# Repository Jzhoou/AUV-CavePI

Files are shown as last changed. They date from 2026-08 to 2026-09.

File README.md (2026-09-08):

# AUV-CavePI

独立完成的水下机器人原型工程，当前重点是把机械结构、电源与密封方案推进到可复现、可检查的实物阶段。仓库保留 CAD、装配、电源管理、问题定位与测试记录，并明确区分已经验证的结果和仍待验证的能力。

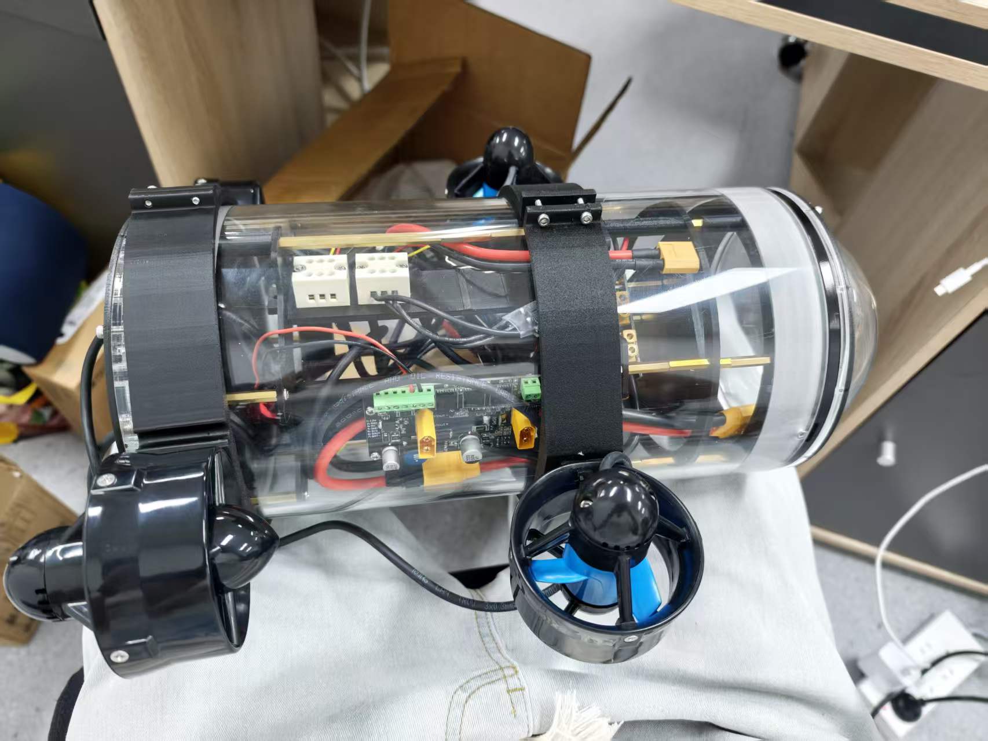
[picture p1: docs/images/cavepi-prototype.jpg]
CavePI 原型


## 项目概览

CavePI 采用 **160 × 300 mm 亚克力圆筒密封舱**、**3 个推进器**与 **14.8 V 4S 电源**。内部结构使用一体抽拉式支撑方案：支撑架一端与法兰配合，另一端不与法兰连接，可整体抽出，以降低安装、接线和维护难度。

本项目由我独立完成，工作覆盖：

- 根据密封舱与实物装配条件持续迭代 CAD，处理支撑结构、板卡布局、接口避让、推进器夹具和线槽等问题；
- 设计并试装一体抽拉式内部支撑，在有限舱内空间中兼顾固定、布线与维护；
- 规划 14.8 V 4S 电源路径及主干、分支接口，记录方案变化与待验证的带载能力；
- 完成穿线螺栓封灌、整机装配、漏点诊断和后续密封处理；
- 通过日志持续记录测试边界、失败现象、整改过程与下一步验证计划。

## 工程迭代

### 机械与 CAD

早期结构方案经过加工可行性和成本评估后转向 160 × 300 mm 成品亚克力密封舱，并据此调整内部支撑和外部安装结构。实物试装暴露了铜柱配合、螺母沉孔、接口干涉和内部高度等问题；CAD 随试装结果迭代，最终采用更便于接线和维护的一端法兰配合式一体抽拉支撑。

### 电源与推进布局

系统以 14.8 V 4S 电池为主电源，围绕电源管理、分电与下游负载规划供电路径。原型配置 3 个推进器；电源接口、线束空间和后续整机带载能力仍按工程日志继续核对，不把方案设计等同于性能验证。

### 密封问题定位

首次整机气密测试中，真空度无法稳定保持。使用泡沫水排查后，将漏点定位到穿线螺栓的线缆周边：封灌不充分且固化期间线缆位移造成开裂。随后对漏点进行二次处理，并在后续复测出现波动后进一步加入线皮打磨粗化、酒精清洁、线缆固定与过夜固化，再进行气密及分段浅水测试。

## 已验证结果

- **负压气密：** 以 15 inHg 为初始真空度保压 15 分钟，读数维持在 14–15 inHg。
- **分段浅水水密：** 受水缸尺寸限制，头部与尾部分别浸水 20 分钟；检查时舱内纸巾保持干燥。

以上结果仅对应当时的测试条件和装配状态。

## 尚未完成的验证

- 整机同时、完全浸没测试；
- 更长时间条件下的水密可靠性验证；
- 推进验证；
- 水下姿态控制验证；
- 定深控制验证。

因此，本仓库当前呈现的是水下机器人原型的工程进展，而不是已经完成全部水下能力验证的成品系统。

## 工程记录

- [项目日志汇总](项目日志汇总.md)
- [CAD v2.0 项目日志](<CAD_designs v2.0/项目日志.md>)
- [电源管理项目日志](电源管理/项目日志.md)

## English Summary

**AUV-CavePI is an independently developed underwater-robot prototype.** It uses a 160 × 300 mm acrylic pressure enclosure, three thrusters, a 14.8 V 4S power source, and an integrated slide-out internal support structure. The repository documents CAD iterations, physical assembly, power-distribution planning, and diagnosis and rework of a leak around cable-penetration bolts.

The verified results are deliberately limited to the recorded test conditions: the enclosure held an initial 15 inHg vacuum for 15 minutes while remaining between 14 and 15 inHg; the head and tail were then immersed separately for 20 minutes, and the paper towel inside remained dry. Full simultaneous immersion of the entire vehicle, long-duration watertightness, propulsion, attitude control, and depth-hold control have **not** yet been validated.

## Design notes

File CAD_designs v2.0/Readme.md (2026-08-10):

# SolidWork Design files of CavePI AUV

Due to large filesize of some parts, they are not uploaded directly to this repo. Please refer to this shared [Dropbox folder](https://www.dropbox.com/scl/fo/iza5p15aaolned5e47gp4/AAuj588nzsUPL_QK-2lGrOM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) to download all the files.

## Description

The parts are categorized into four groups.

- Exterior
  - Thruster
  - Sonar
  - Lights
  - ballast weights
- Interior (Computational enclosure)
  -  Battery junction
  -  Battery mounting plates (top, bottom, left, right, circular)
  -  Battery stack
  -  ESC
  -  Low light camera (downward camera)
  -  End cap
  -  O-ring flange
  -  Euro terminal strip
  -  Jetson Nano
  -  Mounting plate for Jetson Nano
  -  Raspberry Pi
  -  Mounting plate for Raspberry Pi
  -  Pixhawk
  -  Tether interface module
  -  Tube
-  Head
   - Fisheye camera
   - Dome connector
   - Dome retainer ring
   - Dome
 - Fasteners
   - Nuts, bolts, spacers and stand-offs

### Acknowledgements

We gratefully acknowledge the following entities for their the open-source CAD designs of various parts: Blue Robotics, GrabCAD, and McMaster-Carr.

| Part Name | 3D Model Owner / Referred From |
|---|---|
| Tube | Blue Robotics |
| End Cap | Blue Robotics |
| O-Ring Flange | Blue Robotics |
| Camera Low Light | Blue Robotics |
| Tether Interface Module | Blue Robotics |
| Basic ESC | Blue Robotics |
| Dome Retainer Ring | Blue Robotics |
| Dome | Blue Robotics |
| T200_Thruster | Blue Robotics |
| Sonar Bracket | Blue Robotics |
| Ping2 Sonar | Blue Robotics |
| Ballast Weight | Blue Robotics |
| Light | Blue Robotics |
| All fasteners | McMaster Carr |
| Jetson Nano | [GrabCAD](https://grabcad.com/library/nvidia-jetson-nano-2) |
| Raspberry Pi 5 | [GrabCAD](https://grabcad.com/library/raspberry-pi-5-2) |
| Pixhawk | [GrabCAD](https://grabcad.com/library/pixhawk-2-4-8-v1-flight-controller-1) |
| Fish-Eye Camera | [ArduCam](https://www.arducam.com/arducam-1080p-low-light-wdr-ultra-wide-angle-usb-camera-module-for-computer-2mp-cmos-imx291-160-degree-fisheye-mini-uvc-usb2-0-spy-webcam-boa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) |

## Example

The CAD assembly and the exploded view of CavePI is shown below:
<p align="center">
  cavepi_sys_gif
</p>

The 3D models of some of the parts in CavePI are shown below.
<p align="center">
  CAD Parts
</p>

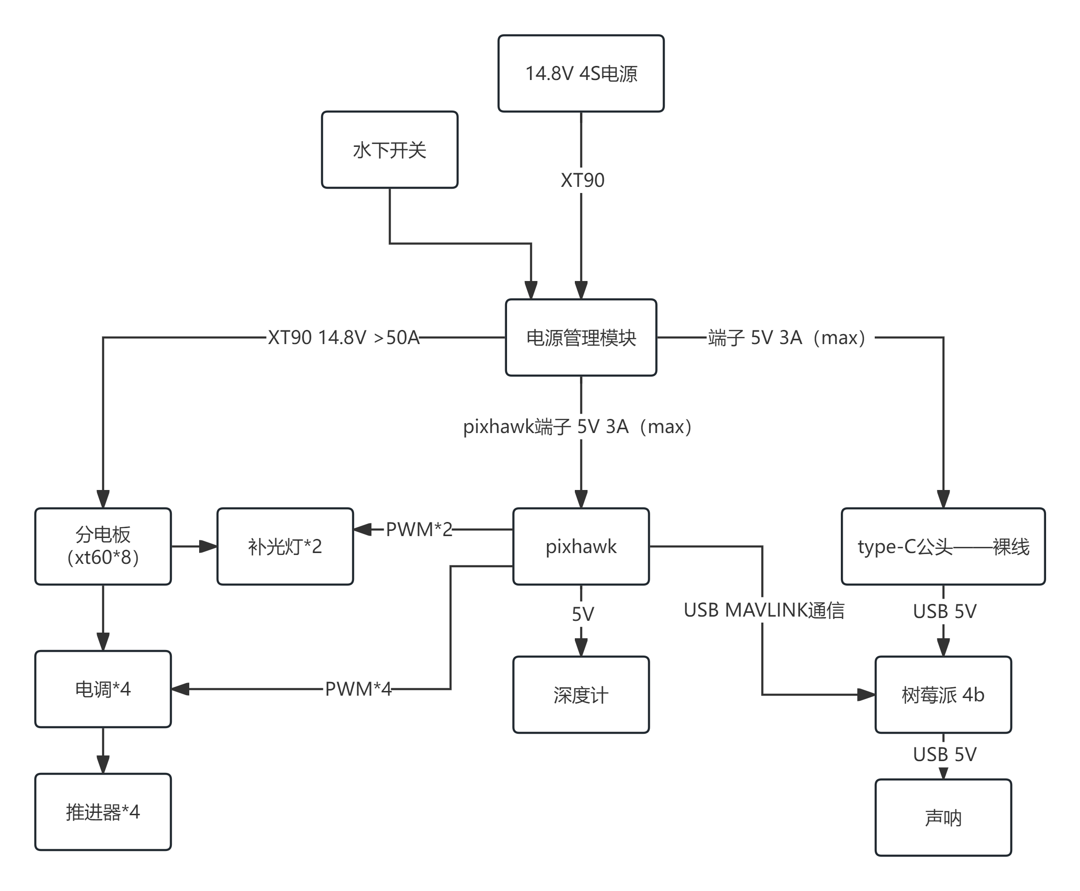
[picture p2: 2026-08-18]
电源管理/AUV电源管理方案2.0.png

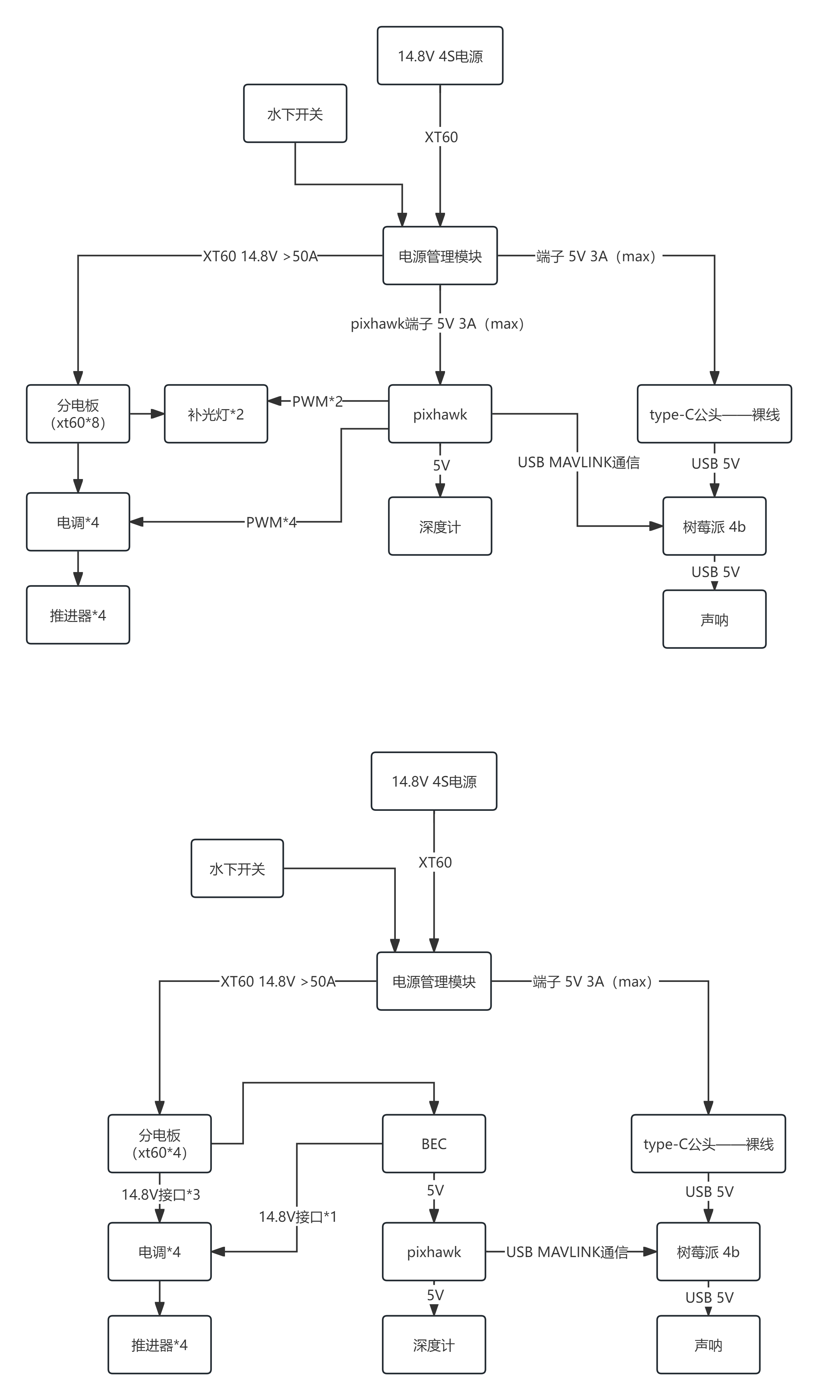
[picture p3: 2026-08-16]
电源管理/AUV电源管理方案.png

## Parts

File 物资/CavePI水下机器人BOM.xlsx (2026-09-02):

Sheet: BOM主表
CavePI 水下机器人 BOM 主表
口径：单台机器人；包含本体与装配耗材，不含通用工具。第一版按30 m设计深度、1-2 h续航目标管理，未完成工程验证的规格明确标记为待选型。
BOM物料数 |  |  | 第一版待购物料 |  |  | 第一版已知待购金额（元） |  |  | 待选型条目 |  |  | 说明：黄色表示存在采购缺口；浅红表示参数或型号尚未确认；灰色列为公式计算列。数量跨单位汇总仅供阶段规模参考。
68 |  |  | 21 |  |  | 0 |  |  | 23
物料编码 | 系统分类 | 装配层级 | 物料名称 | 规格/型号 | 单位 | 调试版需求量 | 第一版需求量 | 后续升级增量 | 现有可用数量 | 调试版待购量 | 第一版待购量 | 升级待购量 | 参考单价（元） | 调试版待购金额 | 第一版待购金额 | 升级待购金额 | 采购状态 | 来源资产编号 | 来源采购日期 | 备注
CPI-MECH-001 | 机械结构 | 一级部件 | 亚克力耐压舱筒体 | 外径160×有效筒长300 mm / 壁厚5 mm | 件 | 1 | 1 | 0 | 1 | 0 | 0 | 0 | 1145.00 | 0.00 | 0.00 | 0.00 | 已有 | ZC-20260818-005 | 2026-08-18 | 已购外径160×300mm整套密封舱，含亚克力圆管、半球罩、法兰、金属圈、端盖、密封圈、硅脂和配套螺丝；筒体壁厚、接口及30m耐压能力仍需到货验收和水压试验
CPI-MECH-002 | 机械结构 | 一级部件 | 耐压舱端盖 | 适配外径160 mm筒体 / 端盖结构与材料待确认 | 件 | 2 | 2 | 0 | 0 | 2 | 2 | 0 |  |  |  |  | 待选型 |  |  | 套装已含半球罩和端盖；具体数量、材料、厚度、密封槽及连接方式待到货核验，暂不冲减待购量
CPI-MECH-003 | 机械结构 | 二级部件 | 端盖压环/锁紧组件 | 与160 mm筒体及端盖匹配 | 套 | 2 | 2 | 0 | 0 | 2 | 2 | 0 |  |  |  |  | 待选型 |  |  | 套装已含法兰、金属圈和配套螺丝；数量、尺寸及锁紧结构待到货核验，暂不冲减待购量
CPI-SEAL-001 | 水密与线缆 | 二级部件 | 端盖O形密封圈 | 与端盖密封槽匹配 / 装机2件+备件2件 | 个 | 4 | 4 | 0 | 0 | 4 | 4 | 0 |  |  |  |  | 待选型 |  |  | 套装已含密封圈；数量、截面、材料及压缩率待到货核验，暂不冲减待购量
CPI-MECH-004 | 机械结构 | 一级部件 | 外部框架 | 耐腐蚀轻量框架 / 尺寸与材料待结构设计确认 | 套 | 1 | 1 | 0 | 0 | 1 | 1 | 0 |  |  |  |  | 待选型 |  |  | 建议模块化安装；需结合重心、浮心与推进器布局
CPI-MECH-005 | 机械结构 | 二级部件 | 舱内安装板 | 适配160×300 mm舱体 | 件 | 1 | 2 | 0 | 0 | 1 | 2 | 0 |  |  |  |  | 待选型 |  |  | 用于飞控、树莓派与电源模块分层安装
CPI-MECH-006 | 机械结构 | 二级部件 | 推进器安装支架 | 适配TS60 / 四推进器布局 | 个 | 1 | 4 | 0 | 0 | 1 | 4 | 0 |  |  |  |  | 待选型 |  |  | 支架角度按4自由度布置确认
CPI-MECH-007 | 机械结构 | 二级部件 | 浮力材料组件 | 闭孔浮力材料 / 目标微正浮力 | 套 | 1 | 1 | 0 | 0 | 1 | 1 | 0 |  |  |  |  | 待选型 |  |  | 需在整机称重后校核体积与布置
CPI-MECH-008 | 机械结构 | 二级部件 | 可调配重组件 | 耐腐蚀配重 / 可移动安装 | 套 | 1 | 1 | 0 | 0 | 1 | 1 | 0 |  |  |  |  | 待选型 | ZC-20260828-003 | 2026-08-28 | 已购5块×约200g纯铅配重；可移动安装结构、表面防腐与整机配平尚未确认，暂不冲减待购量
CPI-PROP-001 | 动力 | 一级部件 | TS60水下推进器 | 蓝黑500/12V | 个 | 1 | 4 | 0 | 4 | 0 | 0 | 0 | 189.00 | 0.00 | 0.00 | 0.00 | 已有 | ZC-20260713-009；ZC-20260818-003 | 2026-08-18 | 第一版四推进器已配齐：原有1个，本次新增3个
CPI-PROP-002 | 动力 | 一级部件 | 35A双向水下电调 | 35A / 双向无刷 / 水下动力 | 个 | 1 | 4 | 0 | 4 | 0 | 0 | 0 | 95.00 | 0.00 | 0.00 | 0.00 | 已有 | ZC-20260713-011；ZC-20260818-004 | 2026-08-18 | 第一版4个双向电调已配齐：原有1个，本次新增3个
CPI-POWER-001 | 电源 | 一级部件 | XT60 Hub分电板 | 一拖四扩展板/集线器 | 个 | 1 | 1 | 0 | 1 | 0 | 0 | 0 | 29.90 | 0.00 | 0.00 | 0.00 | 已有 | ZC-20260713-005 | 2026-07-13 | 动力母线分配
CPI-POWER-002 | 电源 | 一级部件 | 博立方电源模块 | 2S-12S / 5.3V BEC / XT60 | 个 | 1 | 1 | 0 | 1 | 0 | 0 | 0 | 71.24 | 0.00 | 0.00 | 0.00 | 已有 | ZC-20260713-006 | 2026-07-13 | 飞控电源与电压电流监测
CPI-POWER-003 | 电源 | 一级部件 | DC-DC 5V 10A降压模块 | QS-1205CBUM-10A | 个 | 1 | 1 | 0 | 1 | 0 | 0 | 0 | 17.60 | 0.00 | 0.00 | 0.00 | 已有 | ZC-20260729-001 | 2026-07-29 | 树莓派及低压设备供电
CPI-POWER-004 | 电源 | 一级部件 | ROV大电流电源控制板 | 5V/12V输出 / 板载大电流MOS开关 | 个 | 1 | 1 | 0 | 1 | 0 | 0 | 0 | 249.00 | 0.00 | 0.00 | 0.00 | 已有 | ZC-20260807-001 | 2026-08-07 | 主电源控制
CPI-POWER-005 | 电源 | 二级部件 | M10水下旋钮开关 | 大深水旋钮开关 / M10 | 个 | 1 | 1 | 0 | 1 | 0 | 0 | 0 | 93.58 | 0.00 | 0.00 | 0.00 | 已有 | ZC-20260807-002 | 2026-08-07 | 外部电源控制
CPI-POWER-006 | 电源 | 一级部件 | 调试用4S锂电池 | 14.8V 5000mAh / 长条 | 组 | 1 | 0 | 0 | 1 | 0 | 0 | 0 | 74.82 | 0.00 | 0.00 | 0.00 | 已有 | ZC-20260713-007 | 2026-07-13 | 仅用于调试，不作为第一版续航电池
CPI-POWER-007 | 电源 | 一级部件 | 第一版高容量动力电池 | 4S高放电锂电 / 建议20-30Ah区间 / 尺寸与容量待功耗实测 | 组 | 0 | 1 | 0 | 1 | 0 | 0 | 0 | 1552.00 | 0.00 | 0.00 | 0.00 | 部分已有 | ZC-20260825-003 | 2026-08-25 | 已购4S6P 14.8V 18Ah电池；容量低于建议20–30Ah，尺寸、持续放电能力及1–2h续航仍需实测
CPI-POWER-008 | 电源 | 二级部件 | 主回路保险丝座 | 适配4S动力母线 / 额定电流待实测 | 套 | 1 | 1 | 0 | 0 | 1 | 1 | 0 |  |  |  |  | 待选型 |  |  | 靠近电池正极布置
CPI-POWER-009 | 电源 | 二级部件 | 支路保险丝 | 推进器4路+低压与照明支路 / 规格待负载确认 | 个 | 3 | 6 | 0 | 0 | 3 | 6 | 0 |  |  |  |  | 待选型 |  |  | 按各支路最大工作电流选择
CPI-POWER-010 | 电源 | 二级部件 | XT60预制电源线 | XT60公头 / 12AWG / 30cm | 条 | 2 | 4 | 0 | 5 | 0 | 0 | 0 | 5.20 | 0.00 | 0.00 | 0.00 | 已有 | ZC-20260728-005 | 2026-07-28 | 现有采购为5条装
CPI-POWER-011 | 电源 | 三级部件 | 12AWG硅胶电源线 | 红黑双色 / 镀锡铜 | 米 | 2 | 5 | 0 | 0 | 2 | 5 | 0 |  |  |  |  | 待选型 |  |  | 长度按舱内布线复核
CPI-POWER-012 | 电源 | 三级部件 | Type-C大电流供电线 | 0.3m / Type-C公单头 / 0.5mm² | 条 | 1 | 1 | 0 | 1 | 0 | 0 | 0 | 4.98 | 0.00 | 0.00 | 0.00 | 已有 | ZC-20260810-001 | 2026-08-10 | 树莓派供电连接
CPI-CTRL-001 | 控制 | 一级部件 | 树莓派4B开发板 | 4B / 4GB | 块 | 1 | 1 | 0 | 1 | 0 | 0 | 0 | 1511.21 | 0.00 | 0.00 | 0.00 | 已有 | ZC-20260713-012 | 2026-07-13 | 第一版规划与控制计算平台
CPI-CTRL-002 | 控制 | 一级部件 | Pixhawk 2.4.8飞控 | 无GPS / 已刷ArduSub | 块 | 1 | 1 | 0 | 1 | 0 | 0 | 0 | 599.00 | 0.00 | 0.00 | 0.00 | 已有 | ZC-20260713-013 | 2026-07-13 | 姿态、深度与推进器控制
CPI-CTRL-003 | 控制 | 二级部件 | USB转TTL通讯模块 | Y804 / 5V TTL | 个 | 1 | 1 | 0 | 1 | 0 | 0 | 0 | 16.40 | 0.00 | 0.00 | 0.00 | 已有 | ZC-20260729-003 | 2026-07-29 | 调试与串口通信
CPI-CTRL-004 | 控制 | 二级部件 | microSD存储卡 | 64GB / A2级 / 高耐久 | 张 | 1 | 1 | 2 | 0 | 1 | 1 | 2 |  |  |  |  | 待选型 |  |  | 升级阶段为Jetson与树莓派5各预留1张
CPI-CTRL-005 | 控制 | 二级部件 | 树莓派散热组件 | 适配树莓派4B / 被动散热优先 | 套 | 1 | 1 | 0 | 0 | 1 | 1 | 0 |  |  |  |  | 待选型 |  |  | 密闭舱内需校核温升，不建议依赖舱内空气风扇
CPI-CTRL-006 | 控制 | 二级部件 | 舱内漏水检测模块 | 触点式或光电式 / Pixhawk兼容 | 个 | 1 | 1 | 0 | 0 | 1 | 1 | 0 |  |  |  |  | 待选型 |  |  | 建议作为第一版安全必备件
CPI-SENS-001 | 感知 | 一级部件 | MS5837深度计 | MS5837-30Ba TB30 | 个 | 1 | 1 | 0 | 1 | 0 | 0 | 0 | 199.00 | 0.00 | 0.00 | 0.00 | 已有 | ZC-20260713-010 | 2026-07-13 | 定深控制
CPI-SENS-002 | 感知 | 一级部件 | 水下测距传感器 | 3米量程 / 8-800cm | 个 | 1 | 1 | 0 | 1 | 0 | 0 | 0 | 103.00 | 0.00 | 0.00 | 0.00 | 已有 | ZC-20260713-008 | 2026-07-13 | 第一版基础测距；后续声呐升级不覆盖此件
CPI-LIGHT-001 | 照明 | 一级部件 | ROV探照灯 | ArduSub PWM / 2500lm / 8-30V / 100° | 盏 | 1 | 2 | 0 | 2 | 0 | 0 | 0 | 299.00 | 0.00 | 0.00 | 0.00 | 已有 | ZC-20260729-002；ZC-20260828-005 | 2026-08-28 | 第一版两盏探照灯已配齐：原有1盏，本次新增1盏；新增规格为6500K、ArduSub PWM、100°光束角，电压与水密性待实测
CPI-SEAL-002 | 水密与线缆 | 二级部件 | 主穿舱水密接头/电缆穿透件 | 适配30 m设计深度 / 口径和数量按线缆表确认 | 个 | 5 | 8 | 4 | 9 | 0 | 0 | 3 | 30.00 | 0.00 | 0.00 | 90.00 | 部分已有 | ZC-20260818-002 | 2026-08-18 | 本次购M10穿线螺丝9个，第一版需求8个已覆盖并余1个；后续升级仍需按线缆表复核
CPI-SEAL-003 | 水密与线缆 | 二级部件 | 泄压/抽真空测试阀 | 耐压舱检漏接口 | 个 | 1 | 1 | 0 | 0 | 1 | 1 | 0 |  |  |  |  | 待选型 |  |  | 用于负压检漏和压力测试流程
CPI-SEAL-004 | 水密与线缆 | 三级部件 | O形圈硅脂 | 水下密封兼容 / 不腐蚀密封材料 | 份 | 1 | 1 | 0 | 1 | 0 | 0 | 0 | 49.00 | 0.00 | 0.00 | 0.00 | 已有 | ZC-20260828-001 | 2026-08-28 | 已购ROV专用防水密封硅脂；数量覆盖第一版，但与实际O形圈材料的相容性仍需到货核验
CPI-SEAL-005 | 水密与线缆 | 三级部件 | 灌封胶/海工环氧 | 电缆穿舱灌封 / 与线皮和舱体材料兼容 | 份 | 1 | 1 | 1 | 2 | 0 | 0 | 0 | 75.00 | 0.00 | 0.00 | 0.00 | 已有 | ZC-20260825-002；ZC-20260828-002 | 2026-08-28 | 已有黑色快干AB环氧胶与专用穿线密封胶各1份，覆盖第一版及升级阶段数量；仍需完成长期浸泡、材料相容性及固化工艺试验
CPI-SEAL-006 | 水密与线缆 | 三级部件 | 热缩管套装 | 含胶双壁 / 多规格 | 套 | 1 | 1 | 0 | 0 | 1 | 1 | 0 |  |  |  |  | 待选型 |  |  | 舱内线束绝缘与应力保护
CPI-NET-001 | 水密与线缆 | 调试附件 | 调试网线 | CAT6 / 建议35 m含余量 | 米 | 35 | 0 | 0 | 0 | 35 | 0 | 0 |  |  |  |  | 待选型 |  |  | 仅调试版保留，第一版不配置网线脐带
CPI-NET-002 | 水密与线缆 | 调试附件 | 网线水密穿舱组件 | CAT6兼容 / 30 m级水密 | 套 | 1 | 0 | 0 | 0 | 1 | 0 | 0 |  |  |  |  | 待选型 |  |  | 仅调试版
CPI-NET-003 | 水密与线缆 | 调试附件 | 网线应力释放与水面连接组件 | 适配35 m调试网线 | 套 | 1 | 0 | 0 | 0 | 1 | 0 | 0 |  |  |  |  | 待选型 |  |  | 仅调试版，避免拉力直接作用于穿舱件
CPI-CONS-001 | 装配耗材 | 三级部件 | M3×6不锈钢螺钉 | 304十字圆头 | 个 | 8 | 12 | 4 | 100 | 0 | 0 | 0 | 0.02 | 0.00 | 0.00 | 0.00 | 已有 | ZC-20260722-019 | 2026-07-22 | 装机建议量；最终随结构图复核
CPI-CONS-002 | 装配耗材 | 三级部件 | M3×10不锈钢螺钉 | 304十字圆头 | 个 | 8 | 12 | 4 | 100 | 0 | 0 | 0 | 0.03 | 0.00 | 0.00 | 0.00 | 已有 | ZC-20260722-018 | 2026-07-22 | 装机建议量；最终随结构图复核
CPI-CONS-003 | 装配耗材 | 三级部件 | M3×12不锈钢螺钉 | 304内六角 | 个 | 8 | 16 | 4 | 100 | 0 | 0 | 0 | 0.03 | 0.00 | 0.00 | 0.00 | 已有 | ZC-20260722-014 | 2026-07-22 | 装机建议量；最终随结构图复核
CPI-CONS-004 | 装配耗材 | 三级部件 | M3×20不锈钢螺钉 | 304十字圆头机牙 | 个 | 4 | 8 | 4 | 100 | 0 | 0 | 0 | 0.05 | 0.00 | 0.00 | 0.00 | 已有 | ZC-20260803-002 | 2026-08-03 | 装机建议量；最终随结构图复核
CPI-CONS-005 | 装配耗材 | 三级部件 | M3防松锁紧螺母 | 304材质 | 个 | 12 | 24 | 8 | 40 | 0 | 0 | 0 | 0.05 | 0.00 | 0.00 | 0.00 | 已有 | ZC-20260803-003 | 2026-08-03 | 推进器及框架连接优先使用
CPI-CONS-006 | 装配耗材 | 三级部件 | M3六角螺母 | 304材质 | 个 | 12 | 24 | 8 | 100 | 0 | 0 | 0 | 0.02 | 0.00 | 0.00 | 0.00 | 已有 | ZC-20260722-013 | 2026-07-22 | 装机建议量
CPI-CONS-007 | 装配耗材 | 三级部件 | M3平垫圈 | 304 / M3×6×0.5 | 个 | 16 | 32 | 8 | 200 | 0 | 0 | 0 | 0.02 | 0.00 | 0.00 | 0.00 | 已有 | ZC-20260722-007 | 2026-07-22 | 装机建议量
CPI-CONS-008 | 装配耗材 | 三级部件 | M3铜柱12mm | M3×12+3 | 支 | 4 | 4 | 4 | 50 | 0 | 0 | 0 | 0.17 | 0.00 | 0.00 | 0.00 | 已有 | ZC-20260722-001 | 2026-07-22 | 板卡安装
CPI-CONS-009 | 装配耗材 | 三级部件 | M3铜柱20mm | M3×20+3 | 支 | 4 | 4 | 4 | 70 | 0 | 0 | 0 | 0.26 | 0.00 | 0.00 | 0.00 | 已有 | ZC-20260722-004；ZC-20260817-004 | 2026-08-17 | 板卡安装；现有50支M3×20+3，另购20支M3×20+6，装配前确认螺柱端长度
CPI-CONS-010 | 装配耗材 | 三级部件 | 管型端子 | VE1508等 / 按线径选用 | 个 | 12 | 24 | 12 | 1200 | 0 | 0 | 0 | 0.01 | 0.00 | 0.00 | 0.00 | 已有 | ZC-20260722-021 | 2026-07-22 | 从现有1200只套装中领用
CPI-CONS-011 | 装配耗材 | 三级部件 | 3位接线端子连接器 | H3802-15A-03 / 白色 | 个 | 2 | 4 | 2 | 5 | 0 | 0 | 1 | 4.98 | 0.00 | 0.00 | 4.98 | 部分已有 | ZC-20260722-022 | 2026-07-22 | 现有5个
CPI-CONS-012 | 装配耗材 | 三级部件 | 电工绝缘胶带 | PVC阻燃防水 | 卷 | 1 | 1 | 1 | 2 | 0 | 0 | 0 | 2.50 | 0.00 | 0.00 | 0.00 | 已有 | ZC-20260807-006 | 2026-08-07 | 仅作辅助绝缘，不作为耐压舱主密封
CPI-CONS-013 | 装配耗材 | 三级部件 | 电子焊接锡丝 | 无铅低温 / 自带松香 | 份 | 1 | 1 | 1 | 1 | 0 | 0 | 1 | 15.80 | 0.00 | 0.00 | 15.80 | 部分已有 | ZC-20260713-001；ZC-20260830-001 | 2026-08-30 | 原有1份无铅低温锡丝；本次新增2卷63%含锡焊丝，可用于调试，但不等同无铅规格，暂不增加BOM合规可用数量
CPI-CONS-014 | 装配耗材 | 三级部件 | 尼龙扎带与线束固定座 | 多规格 / 耐潮 | 套 | 1 | 1 | 1 | 0 | 1 | 1 | 1 |  |  |  |  | 部分已有 | ZC-20260826-006 | 2026-08-26 | 已购4×150mm黑色尼龙扎带500根；未见线束固定座，暂不冲减套件待购量
CPI-CONS-015 | 装配耗材 | 三级部件 | 中强度螺纹锁固剂 | 适用于不锈钢紧固件 | 份 | 1 | 1 | 1 | 0 | 1 | 1 | 1 |  |  |  |  | 待选型 |  |  | 避免使用永久高强度型号
CPI-SAFE-001 | 安全回收 | 一级部件 | 安全回收绳 | 低伸长高强度绳 / 建议35 m含余量 | 米 | 10 | 35 | 0 | 0 | 10 | 35 | 0 |  |  |  |  | 待选型 |  |  | 完整版无网线脐带，保留独立安全回收措施
CPI-SAFE-002 | 安全回收 | 二级部件 | 不锈钢卸扣/连接环 | 耐腐蚀 / 与回收绳及框架匹配 | 个 | 2 | 2 | 0 | 0 | 2 | 2 | 0 |  |  |  |  | 待选型 |  |  | 设置独立承力点
CPI-SAFE-003 | 安全回收 | 二级部件 | 高可视识别标识 | 橙色或荧光耐水标识 | 套 | 1 | 1 | 0 | 0 | 1 | 1 | 0 |  |  |  |  | 待选型 |  |  | 便于水面与水下识别
CPI-UPG-001 | 后续升级 | 一级部件 | Jetson Nano计算平台 | 视觉感知计算 / 型号与内存版本待选 | 套 | 0 | 0 | 1 | 0 | 0 | 0 | 1 |  |  |  |  | 可选升级 |  |  | 参考公开CavePI视觉计算架构
CPI-UPG-002 | 后续升级 | 一级部件 | 树莓派5开发板 | 规划与控制计算 / 内存版本待选 | 套 | 0 | 0 | 1 | 0 | 0 | 0 | 1 |  |  |  |  | 可选升级 |  |  | 后续版本升级计算平台
CPI-UPG-003 | 后续升级 | 一级部件 | 前视低照度摄像头 | 水下低照度 / 视场角与接口待选 | 套 | 0 | 0 | 1 | 0 | 0 | 0 | 1 |  |  |  |  | 可选升级 |  |  | 第一版不配置摄像头
CPI-UPG-004 | 后续升级 | 一级部件 | 下视低照度摄像头 | 引导线识别 / 视场角与接口待选 | 套 | 0 | 0 | 1 | 0 | 0 | 0 | 1 |  |  |  |  | 可选升级 |  |  | 第一版不配置摄像头
CPI-UPG-005 | 后续升级 | 二级部件 | 摄像头水密窗口/舱体 | 前视+下视 / 30 m级 / 光学窗口 | 套 | 0 | 0 | 2 | 0 | 0 | 0 | 2 |  |  |  |  | 可选升级 |  |  | 需与摄像头视场和舱体布局匹配
CPI-UPG-006 | 后续升级 | 一级部件 | Ping2级声呐测距模块 | 障碍测距 / 具体型号待选 | 套 | 0 | 0 | 1 | 0 | 0 | 0 | 1 |  |  |  |  | 可选升级 |  |  | 用于远距离测距避障
CPI-UPG-007 | 后续升级 | 可选系统 | DVL水下速度计 | 水下速度/里程推算 / 量程与接口待选 | 套 | 0 | 0 | 1 | 0 | 0 | 0 | 1 |  |  |  |  | 可选升级 |  |  | 定位建图方案选配，成本较高
CPI-UPG-008 | 后续升级 | 可选系统 | 水声定位系统 | USBL/LBL方案待论证 | 套 | 0 | 0 | 1 | 0 | 0 | 0 | 1 |  |  |  |  | 可选升级 |  |  | 定位建图方案选配
CPI-UPG-009 | 后续升级 | 可选系统 | 成像声呐 | 水下建图 / 频率与量程待选 | 套 | 0 | 0 | 1 | 0 | 0 | 0 | 1 |  |  |  |  | 可选升级 |  |  | 建图方案选配
CPI-UPG-010 | 后续升级 | 二级部件 | 高速固态存储 | 512GB / 高耐久 | 块 | 0 | 0 | 1 | 0 | 0 | 0 | 1 |  |  |  |  | 可选升级 |  |  | 记录双摄像头与声呐数据

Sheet: 阶段采购汇总
CavePI 阶段采购汇总
调试版、第一版和后续升级的数量与采购缺口均自动引用BOM主表。跨单位数量合计仅用于规模参考。
阶段 | 需求物料种类 | 需求数量合计（混合单位） | 已有覆盖物料种类 | 待购物料种类 | 待购数量合计（混合单位） | 已知单价覆盖物料种类 | 已知待购金额（元） | 待选型物料种类
调试版 | 57 | 193 | 33 | 24 | 76 | 33 | 0.00 | 23
第一版 | 54 | 277 | 33 | 21 | 74 | 33 | 0.00 | 20
后续升级 | 28 | 84 | 15 | 16 | 20 | 15 | 110.78 | 2
来源核对：采购清单共100类、141件，采购总额9402.88元；资产清单中运费、快递费与打包费未纳入资产。本表只匹配机器人本体与装配耗材。

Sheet: 现有资产匹配
现有资产与 CavePI BOM 匹配
逐条保留资产清单来源。匹配结论用于库存识别，不改变原资产记录；通用工具和非本体费用不计入单台BOM。
资产编号 | 管理类别 | 资产属性 | 资产名称 | 规格/型号 | 采购数量 | 单价（元） | 资产原值（元） | 购置日期 | 供应商/店铺 | 匹配BOM编码 | 匹配结论 | 说明
ZC-20260713-001 | 材料耗材 | 低值易耗品 | 绿林高纯度锡丝 | 自带松香/无铅低温 | 1 | 15.80 | 15.80 | 2026-07-13 | 绿林官方旗舰店 | CPI-CONS-013 | 装配耗材
ZC-20260713-002 | 材料耗材 | 低值易耗品 | 绿林烙铁头（刀头） | 通用936内热式 | 4 | 2.61 | 10.44 | 2026-07-13 | 绿林官方旗舰店 |  | 通用工具不纳入 | 用于装配或调试，不计入单台机器人
ZC-20260713-003 | 工具器具 | 可周转资产 | 绿林电烙铁 | 60W可调温 | 1 | 25.80 | 25.80 | 2026-07-13 | 绿林官方旗舰店 |  | 通用工具不纳入 | 用于装配或调试，不计入单台机器人
ZC-20260713-004 | 设备及装置 | 可周转资产 | 80W航模平衡充电器 | BT2.0第3版/支持1-6S | 1 | 149.90 | 149.90 | 2026-07-13 | 零轴电子科技企业店 |  | 通用工具不纳入 | 用于装配或调试，不计入单台机器人
ZC-20260713-005 | 电子元器件 | 项目组件 | XT60 Hub分电板 | 一拖四扩展板/集线器 | 1 | 29.90 | 29.90 | 2026-07-13 | Autoro电子科技 | CPI-POWER-001 | 直接使用 | 原备注：14
ZC-20260713-006 | 电子元器件 | 项目组件 | 博立方电源模块 | 支持2S-12S/带5.3V BEC/XT60 | 1 | 71.24 | 71.24 | 2026-07-13 | 博立方无人机企业店 | CPI-POWER-002 | 直接使用 | 原备注：14
ZC-20260713-007 | 设备及装置 | 可周转资产 | 航模锂电池 | 14.8V 5000mAh 长条 | 1 | 74.82 | 74.82 | 2026-07-13 | 阳河科技 | CPI-POWER-006 | 直接使用 | 5000mAh仅做调试使用，后续再选择大容量电池
ZC-20260713-008 | 仪器仪表 | 可周转资产 | 水下测距传感器 | 3米量程/8-800cm | 1 | 103.00 | 103.00 | 2026-07-13 | 深圳市电应普科技 | CPI-SENS-002 | 直接使用 | 原备注：14
ZC-20260713-009 | 设备及装置 | 可周转资产 | TS60水下推进器 | 蓝黑500/12V | 1 | 189.00 | 189.00 | 2026-07-13 | 淘宝店铺 | CPI-PROP-001 | 部分使用 | 现有数量不足第一版需求，缺口见BOM主表
ZC-20260713-010 | 仪器仪表 | 可周转资产 | 深度计 | MS5837-30Ba TB30 | 1 | 199.00 | 199.00 | 2026-07-13 | 淘宝店铺 | CPI-SENS-001 | 直接使用
ZC-20260713-011 | 设备及装置 | 可周转资产 | 双向无刷电机电调 | 35A水下动力 | 1 | 95.00 | 95.00 | 2026-07-13 | 淘宝店铺 | CPI-PROP-002 | 部分使用 | 现有数量不足第一版需求，缺口见BOM主表
ZC-20260713-012 | 设备及装置 | 可周转资产 | 树莓派4B开发板 | 4B/4G基础套餐 | 1 | 1511.21 | 1511.21 | 2026-07-13 | 淘宝店铺 | CPI-CTRL-001 | 直接使用
ZC-20260713-013 | 设备及装置 | 可周转资产 | Pixhawk 2.4.8飞控 | 无GPS/刷好Ardusub | 1 | 599.00 | 599.00 | 2026-07-13 | 初将科技 | CPI-CTRL-002 | 直接使用
ZC-20260721-001 | 工具器具 | 可周转资产 | 德力西小螺丝刀套装 | 45合一/S2+CR-V材质 | 1 | 27.70 | 27.70 | 2026-07-21 | 德力西手动工具旗舰店 |  | 通用工具不纳入 | 用于装配或调试，不计入单台机器人
ZC-20260722-001 | 材料耗材 | 低值易耗品 | 单头六角铜柱 | M3×12+3/50支 | 1 | 8.41 | 8.41 | 2026-07-22 | 固万基官方旗舰店 | CPI-CONS-008 | 装配耗材 | 确认订单优惠后价格
ZC-20260722-002 | 材料耗材 | 低值易耗品 | 单头六角铜柱 | M3×6+3/100支 | 1 | 10.93 | 10.93 | 2026-07-22 | 固万基官方旗舰店 |  | 非本体采购不纳入 | 确认订单优惠后价格
ZC-20260722-003 | 材料耗材 | 低值易耗品 | 单头六角铜柱 | M3×15+3/50支 | 1 | 10.93 | 10.93 | 2026-07-22 | 固万基官方旗舰店 |  | 非本体采购不纳入 | 确认订单优惠后价格
ZC-20260722-004 | 材料耗材 | 低值易耗品 | 单头六角铜柱 | M3×20+3/50支 | 1 | 12.46 | 12.46 | 2026-07-22 | 固万基官方旗舰店 | CPI-CONS-009 | 装配耗材 | 确认订单优惠后价格
ZC-20260722-005 | 材料耗材 | 低值易耗品 | 304不锈钢平垫圈 | M5×8×0.5/200只 | 1 | 4.04 | 4.04 | 2026-07-22 | 固万基官方旗舰店 |  | 非本体采购不纳入 | 确认订单优惠后价格
ZC-20260722-006 | 材料耗材 | 低值易耗品 | 304不锈钢平垫圈 | M4×7×0.5/200只 | 1 | 3.19 | 3.19 | 2026-07-22 | 固万基官方旗舰店 |  | 非本体采购不纳入 | 确认订单优惠后价格
ZC-20260722-007 | 材料耗材 | 低值易耗品 | 304不锈钢平垫圈 | M3×6×0.5/200只 | 1 | 3.19 | 3.19 | 2026-07-22 | 固万基官方旗舰店 | CPI-CONS-007 | 装配耗材 | 确认订单优惠后价格
ZC-20260722-008 | 材料耗材 | 低值易耗品 | 单头六角铜柱 | M3×100+6/5支 | 1 | 9.46 | 9.46 | 2026-07-22 | 固万基官方旗舰店 |  | 非本体采购不纳入 | 确认订单优惠后价格
ZC-20260722-009 | 材料耗材 | 低值易耗品 | 单头六角铜柱 | M3×24+3/20支 | 1 | 7.06 | 7.06 | 2026-07-22 | 固万基官方旗舰店 |  | 非本体采购不纳入 | 确认订单优惠后价格
ZC-20260722-010 | 仪器仪表 | 可周转资产 | 数字万用表 | 多功能智能防烧/标配+备用电池 | 1 | 18.60 | 18.60 | 2026-07-22 | 嘉华仪器仪表批发中心 |  | 通用工具不纳入 | 用于装配或调试，不计入单台机器人
ZC-20260722-011 | 材料耗材 | 低值易耗品 | 304不锈钢六角螺母 | M5/50个 | 1 | 2.26 | 2.26 | 2026-07-22 | 楚卫旗舰店 |  | 非本体采购不纳入 | 确认订单优惠后价格
ZC-20260722-012 | 材料耗材 | 低值易耗品 | 304不锈钢六角螺母 | M4/100个 | 1 | 3.18 | 3.18 | 2026-07-22 | 楚卫旗舰店 |  | 非本体采购不纳入 | 确认订单优惠后价格
ZC-20260722-013 | 材料耗材 | 低值易耗品 | 304不锈钢六角螺母 | M3/100个 | 1 | 2.09 | 2.09 | 2026-07-22 | 楚卫旗舰店 | CPI-CONS-006 | 装配耗材 | 确认订单优惠后价格
ZC-20260722-014 | 材料耗材 | 低值易耗品 | 304内六角螺钉 | M3×12/100个 | 1 | 2.60 | 2.60 | 2026-07-22 | 楚卫旗舰店 | CPI-CONS-003 | 装配耗材 | 确认订单优惠后价格
ZC-20260722-015 | 材料耗材 | 低值易耗品 | 304十字圆头螺钉 | M5×12/50个 | 1 | 4.78 | 4.78 | 2026-07-22 | 佰瑞特官方旗舰店 |  | 非本体采购不纳入 | 确认订单优惠后价格
ZC-20260722-016 | 材料耗材 | 低值易耗品 | 304十字圆头螺钉 | M4×12/50个 | 1 | 2.75 | 2.75 | 2026-07-22 | 佰瑞特官方旗舰店 |  | 非本体采购不纳入 | 确认订单优惠后价格
ZC-20260722-017 | 材料耗材 | 低值易耗品 | 304十字圆头螺钉 | M4×10/100个 | 1 | 4.95 | 4.95 | 2026-07-22 | 佰瑞特官方旗舰店 |  | 非本体采购不纳入 | 确认订单优惠后价格
ZC-20260722-018 | 材料耗材 | 低值易耗品 | 304十字圆头螺钉 | M3×10/100个 | 1 | 2.96 | 2.96 | 2026-07-22 | 佰瑞特官方旗舰店 | CPI-CONS-002 | 装配耗材 | 确认订单优惠后价格
ZC-20260722-019 | 材料耗材 | 低值易耗品 | 304十字圆头螺钉 | M3×6/100个 | 1 | 2.34 | 2.34 | 2026-07-22 | 佰瑞特官方旗舰店 | CPI-CONS-001 | 装配耗材 | 确认订单优惠后价格
ZC-20260722-020 | 工具器具 | 可周转资产 | 接线端子压线钳 | HSC8 6-4A/0.25-10mm²/四边形 | 1 | 16.90 | 16.90 | 2026-07-22 | 德力西聚优品专卖店 |  | 通用工具不纳入 | 用于装配或调试，不计入单台机器人
ZC-20260722-021 | 材料耗材 | 低值易耗品 | 管型端子套装 | VE1508针形铜鼻子/8种规格/1200只 | 1 | 17.82 | 17.82 | 2026-07-22 | UTL尤提乐岚行专卖店 | CPI-CONS-010 | 装配耗材 | 确认订单优惠后价格
ZC-20260722-022 | 材料耗材 | 低值易耗品 | 迷你接线端子连接器 | H3802-15A-03/3位/白色 | 5 | 4.98 | 24.90 | 2026-07-22 | elinkerelectric旗舰店 | CPI-CONS-011 | 装配耗材 | 确认订单优惠后价格
ZC-20260724-001 | 设备及装置 | 可周转资产 | 12V锂电池充电器 | 12-12.6V/1A-2A/5.5mm圆孔/线长1米 | 1 | 12.50 | 12.50 | 2026-07-24 | 浩可充电器实力工厂 |  | 通用工具不纳入 | 用于装配或调试，不计入单台机器人
ZC-20260724-002 | 设备及装置 | 可周转资产 | 公牛六位总控插座 | B9330/全长1.8米 | 1 | 38.00 | 38.00 | 2026-07-24 | 公牛多德专卖店 |  | 通用工具不纳入 | 用于装配或调试，不计入单台机器人
ZC-20260728-002 | 材料耗材 | 低值易耗品 | 单头六角铜柱 | M3*24+6（20支） | 1 | 8.01 | 8.01 | 2026-07-28 | 固万基官方旗舰店 |  | 非本体采购不纳入 | 优惠后价；先用后付
ZC-20260728-003 | 材料耗材 | 低值易耗品 | 单头六角铜柱 | M3*37+6（20支） | 1 | 14.40 | 14.40 | 2026-07-28 | 固万基官方旗舰店 |  | 非本体采购不纳入 | 优惠后价；先用后付
ZC-20260728-004 | 工具器具 | 可周转资产 | 钳子三件套 | 8寸工业级套装（老虎钳+斜嘴钳+尖嘴钳） | 1 | 26.27 | 26.27 | 2026-07-28 | 天天特卖工厂 |  | 通用工具不纳入 | 用于装配或调试，不计入单台机器人
ZC-20260728-005 | 电子元器件 | 项目组件 | XT60公母插头 | XT60公头12AWG，3.4平方，30厘米，5条 | 1 | 26.00 | 26.00 | 2026-07-28 | 创未良品电子科技有限公司 | CPI-POWER-010 | 直接使用 | 优惠后价；先用后付
ZC-20260729-001 | 电子元器件 | 项目组件 | DC-DC降压模块 | QS-1205CBUM-10A / DC-DC 5V 10A | 1 | 17.60 | 17.60 | 2026-07-29 | 深圳市优信电子科技有限公司 | CPI-POWER-003 | 直接使用 | 实付款17.60元
ZC-20260729-002 | 设备及装置 | 可周转资产 | 水下机器人ROV探照灯 | Ardusub脉宽控制 / 光束角100° / 2500流明 / 8-30V宽压 / PWM驱动 | 1 | 306.00 | 306.00 | 2026-07-29 | EXOCEAN拓洲智能 | CPI-LIGHT-001 | 部分使用 | 现有数量不足第一版需求，缺口见BOM主表
ZC-20260729-003 | 电子元器件 | 项目组件 | USB转RS232/TTL通讯模块 | Y804（USB转TTL）/ 通讯电平5V | 1 | 16.40 | 16.40 | 2026-07-29 | 雨伽量旗舰店 | CPI-CTRL-003 | 直接使用 | 实付款16.40元
ZC-20260803-001 | 材料耗材 | 低值易耗品 | 304不锈钢十字圆头机牙螺钉 | M3*22 / 100个 | 1 | 5.15 | 5.15 | 2026-08-03 | 佰瑞特官方旗舰店 |  | 非本体采购不纳入 | 先用后付；确认收货后应付5.15元
ZC-20260803-002 | 材料耗材 | 低值易耗品 | 304不锈钢十字圆头机牙螺钉 | M3*20 / 100个 | 1 | 4.87 | 4.87 | 2026-08-03 | 佰瑞特官方旗舰店 | CPI-CONS-004 | 装配耗材 | 先用后付；确认收货后应付4.87元
ZC-20260803-003 | 材料耗材 | 低值易耗品 | 304不锈钢防松锁紧螺母 | M3 / 304材质 / 40个 | 1 | 1.94 | 1.94 | 2026-08-03 | 固万基五金科技 | CPI-CONS-005 | 装配耗材 | 先用后付；确认收货后应付1.94元
ZC-20260807-001 | 设备及装置 | 可周转资产 | ROV电源板开关天启大电流控制器 | 5V/12V输出 / 板载大电流MOS开关 | 1 | 249.00 | 249.00 | 2026-08-07 | 店铺名未显示 | CPI-POWER-004 | 直接使用 | 包邮；截图未显示完整店铺名
ZC-20260807-002 | 设备及装置 | 可周转资产 | 海目云水下机器人大深水旋钮开关 | M10开关 | 1 | 93.58 | 93.58 | 2026-08-07 | VIOCEAN海目云海洋科技企业店 | CPI-POWER-005 | 直接使用 | 补贴后价格
ZC-20260807-003 | 工具器具 | 可周转资产 | 得力办公家用不锈钢美工剪刀 | 办公家用剪刀 | 1 | 8.00 | 8.00 | 2026-08-07 | 得力文具品牌旗舰店 |  | 通用工具不纳入 | 用于装配或调试，不计入单台机器人
ZC-20260807-004 | 工具器具 | 可周转资产 | 小鱼儿有机玻璃透明直尺 | 塑料透明尺 | 1 | 2.00 | 2.00 | 2026-08-07 | 得力文具品牌旗舰店 |  | 通用工具不纳入 | 用于装配或调试，不计入单台机器人
ZC-20260807-005 | 工具器具 | 可周转资产 | 得力小号迷你美工刀 | 拆快递迷你美工刀 | 1 | 3.00 | 3.00 | 2026-08-07 | 得力文具品牌旗舰店 |  | 通用工具不纳入 | 用于装配或调试，不计入单台机器人
ZC-20260807-006 | 材料耗材 | 低值易耗品 | 电工绝缘胶带 | PVC阻燃防水绝缘胶带 | 2 | 2.50 | 5.00 | 2026-08-07 | 得力文具品牌旗舰店 | CPI-CONS-012 | 装配耗材 | 2卷合计5元
ZC-20260810-001 | 电子元器件 | 项目组件 | 纯铜加粗0.5平方5A大电流Type-C公单头线 | 0.3m / Type-C公单 / 黑色 | 1 | 4.98 | 4.98 | 2026-08-10 | 邵深源线材工厂批发店 | CPI-POWER-012 | 直接使用 | 先用后付；订单号3316184510600008294
ZC-20260814-001 | 工具器具 | 可周转资产 | 热熔胶枪 | 7mm胶棒适用 / 不含胶棒 | 1 | 20.20 | 20.20 | 2026-08-14 | 咚宜佳超市（大学城店） |  | 通用工具不纳入 | 用于装配或调试，不计入单台机器人
ZC-20260814-002 | 材料耗材 | 低值易耗品 | 热熔胶棒 | 7mm / 1条装 | 10 | 0.43 | 4.30 | 2026-08-14 | 咚宜佳超市（大学城店） |  | 非本体采购不纳入 | 10条合计4.30元
ZC-20260817-001 | 材料耗材 | 低值易耗品 | 美标特软硅胶线 | 28AWG / 黑色 / 10米/卷 | 1 | 8.49 | 8.49 | 2026-08-17 | skygod旗舰店 |  | 待BOM确认 | 28AWG仅适合低电流信号/控制线，不替代CPI-POWER-011的12AWG主电源线；是否纳入单台BOM待线缆表确认
ZC-20260817-002 | 材料耗材 | 低值易耗品 | 美标特软硅胶线 | 28AWG / 红色 / 10米/卷 | 1 | 8.49 | 8.49 | 2026-08-17 | skygod旗舰店 |  | 待BOM确认 | 28AWG仅适合低电流信号/控制线，不替代CPI-POWER-011的12AWG主电源线；是否纳入单台BOM待线缆表确认
ZC-20260817-003 | 电子元器件 | 项目组件 | XT60母对母延长线 | 0.2m / XT60母对母 / 10AWG（5.3mm²） | 1 | 15.88 | 15.88 | 2026-08-17 | 安捷达线束 |  | 待BOM确认 | 规格与CPI-POWER-010的XT60公头/12AWG/30cm不同，暂不冲抵其需求；具体用途待电源线缆表确认
ZC-20260817-004 | 材料耗材 | 低值易耗品 | 六角铜柱机箱螺丝钉 | M3×20+6 / 20颗 | 1 | 5.66 | 5.66 | 2026-08-17 | 固万基官方旗舰店 | CPI-CONS-009 | 装配耗材 | 与20mm铜柱用途一致；螺柱端为6mm，与既有M3×20+3不同，装配前确认孔深
ZC-20260817-005 | 材料耗材 | 低值易耗品 | 304不锈钢杯头内六角螺钉 | M3×16 / 100个 | 1 | 3.63 | 3.63 | 2026-08-17 | 楚卫旗舰店 |  | 待BOM确认 | M3×16杯头内六角规格未在当前BOM主表列出；是否纳入装配耗材待结构图确认
ZC-20260818-001 | 材料耗材 | 低值易耗品 | M10密封舱实心螺栓 | 铝制密封螺丝 / M10 | 4 | 25.00 | 100.00 | 2026-08-18 | 天启ROV97 |  | 待BOM确认 | 当前BOM未单列M10密封舱实心螺栓；具体安装位置与数量待密封舱结构图确认
ZC-20260818-002 | 材料耗材 | 低值易耗品 | M10穿线螺丝 | 银色 / 不锈钢 / M10 | 9 | 30.00 | 270.00 | 2026-08-18 | 天启ROV97 | CPI-SEAL-002 | 直接使用 | 按主穿舱水密接头/电缆穿透件登记；第一版需求8个，本次购9个，余1个备用
ZC-20260818-003 | 设备及装置 | 可周转资产 | TS60水下推进器 | 蓝黑500KV正桨 / 推荐12V使用 | 3 | 189.00 | 567.00 | 2026-08-18 | 天启ROV97 | CPI-PROP-001 | 直接使用 | 与原有1个合计4个，第一版四推进器需求已配齐
ZC-20260818-004 | 设备及装置 | 可周转资产 | 35A双向无刷电调 | 35A / 双向 / 水下动力 | 3 | 95.00 | 285.00 | 2026-08-18 | 天启ROV97 | CPI-PROP-002 | 直接使用 | 与原有1个合计4个，第一版每推进器1个电调的需求已配齐
ZC-20260818-005 | 设备及装置 | 可周转资产 | 海目云水下机器人密封舱 | 外径160mm×300mm / 亚克力圆管+半球罩+法兰+金属圈+端盖+密封圈+硅脂+配套螺丝 | 1 | 1145.00 | 1145.00 | 2026-08-18 | VIOCEAN海目云海洋科技企业店 | CPI-MECH-001；CPI-MECH-002；CPI-MECH-003；CPI-SEAL-001；CPI-SEAL-004 | 部分使用 | 整套含亚克力圆管、半球罩、法兰、金属圈、端盖、密封圈、硅脂和配套螺丝；已确认组件构成，但端盖/压环/密封圈/硅脂的数量与规格待到货核验，因此暂不冲减相关BOM待购量；筒体壁厚、接口及30m耐压能力仍需验收和水压试验
ZC-20260818-006 | 电子元器件 | 项目组件 | 八合一大电流分电板 | 输入XT90 / 输出XT60 / 焊好出货 | 1 | 97.50 | 97.50 | 2026-08-18 | 梁小二模型 | CPI-POWER-001 | 部分使用 | 升级/替代分电板：XT90输入、多路XT60输出；现有一分四分电板已覆盖主BOM，使用前需确认线序、极性和载流能力
ZC-20260818-007 | 电子元器件 | 项目组件 | XT90H黑色母头带线 | XT90H黑母头 / 8AWG（8.29mm²）/ 红黑线 / 10cm | 1 | 10.12 | 10.12 | 2026-08-18 | 阳光模型上海DIY（截图店名截断） | CPI-POWER-001 | 部分使用 | 八合一分电板输入侧配套线；接入前需确认XT90H公母头、极性及整机供电架构
ZC-20260818-008 | 电子元器件 | 项目组件 | XT90H黄色公头带线 | XT90H黄公头 / 8AWG（8.29mm²）/ 红黑线 / 10cm | 1 | 11.11 | 11.11 | 2026-08-18 | 阳光模型上海DIY（截图店名截断） | CPI-POWER-001 | 部分使用 | 八合一分电板输入侧配套线；接入前需确认XT90H公母头、极性及整机供电架构
ZC-20260825-001 | 工具器具 | 通用工具 | 密封舱气密性测试套装 | 真空枪+宝塔气嘴 / 工具箱套装 | 1 | 245.00 | 245.00 | 2026-08-25 | VIOCEAN海目云海洋科技企业店 | CPI-SEAL-003 | 通用工具不纳入 | 用于密封舱负压气密性测试；属于外部测试工具，不替代装机的泄压/抽真空测试阀
ZC-20260825-002 | 材料耗材 | 低值易耗品 | 黑色快干AB环氧树脂胶 | 黑色快干款 / 5分钟初固 / 两支装 / 送工具 | 1 | 15.10 | 15.10 | 2026-08-25 | 固万旗舰店 | CPI-SEAL-005 | 部分使用 | 可作为灌封/粘接候选；水下长期浸泡、线皮与舱体材料相容性及固化工艺仍需试验
ZC-20260825-003 | 设备及装置 | 项目组件 | 4S6P水下机器人锂电池 | 14.8V / 18Ah / 4S6P | 1 | 1552.00 | 1552.00 | 2026-08-25 | 仙藤电池 | CPI-POWER-007 | 部分使用 | 4S电压匹配，18Ah低于BOM建议20–30Ah；尺寸、持续放电能力和1–2h续航仍需实测
ZC-20260826-001 | 材料耗材 | 低值易耗品 | M2.5 304不锈钢六角螺母 | M2.5 / 100个 | 1 | 2.46 | 2.46 | 2026-08-26 | 金超官方旗舰店 |  | 待BOM确认 | 当前BOM仅单列M3紧固件；是否用于法兰、端盖或舱内安装待结构图确认
ZC-20260826-002 | 材料耗材 | 低值易耗品 | M2.5尼龙平垫片 | M2.5×5×1mm / 200个 | 1 | 4.00 | 4.00 | 2026-08-26 | 品诺塑胶垫圈供应商 |  | 待BOM确认 | 当前BOM未单列M2.5尼龙垫片；用途、耐压与材料相容性待结构图确认
ZC-20260826-003 | 材料耗材 | 低值易耗品 | M2.5×8 304不锈钢十字圆头机牙螺钉 | M2.5×8 / 200个 | 1 | 5.71 | 5.71 | 2026-08-26 | 伯瑞特官方旗舰店 |  | 待BOM确认 | 当前BOM未单列M2.5紧固件；装配位置与实际需求量待结构图确认
ZC-20260826-004 | 材料耗材 | 低值易耗品 | M2.5×6 304不锈钢十字圆头机牙螺钉 | M2.5×6 / 200个 | 1 | 5.07 | 5.07 | 2026-08-26 | 伯瑞特官方旗舰店 |  | 待BOM确认 | 当前BOM未单列M2.5紧固件；装配位置与实际需求量待结构图确认
ZC-20260826-005 | 材料耗材 | 低值易耗品 | M2.5×10 304不锈钢十字圆头机牙螺钉 | M2.5×10 / 200个 | 1 | 6.19 | 6.19 | 2026-08-26 | 伯瑞特官方旗舰店 |  | 待BOM确认 | 当前BOM未单列M2.5紧固件；装配位置与实际需求量待结构图确认
ZC-20260826-006 | 材料耗材 | 低值易耗品 | 黑色自锁式尼龙扎带 | 4×150mm / 黑色 / 500根 | 1 | 17.39 | 17.39 | 2026-08-26 | 伯瑞特官方旗舰店 | CPI-CONS-014 | 部分使用 | 已购扎带，未见配套线束固定座；耐潮与老化性能待装配验证，暂不冲减该套件待购量
ZC-20260826-007 | 材料耗材 | 低值易耗品 | M3×20 304不锈钢杯头内六角螺钉 | M3×20 / 50个 | 1 | 1.12 | 1.12 | 2026-08-26 | 资鑫旗舰店 | CPI-CONS-004 | 部分使用 | 长度与BOM一致但头型为杯头内六角；原有M3×20十字圆头库存已覆盖需求，本批作替代/备件
ZC-20260828-001 | 材料耗材 | 低值易耗品 | ROV专用防水密封硅脂 | 水下密封专用硅脂 | 1 | 49.00 | 49.00 | 2026-08-28 | VIOCEAN海目云海洋科技企业店 | CPI-SEAL-004 | 直接使用 | 与O形圈硅脂直接匹配；到货后仍需核对密封圈材料相容性
ZC-20260828-002 | 材料耗材 | 低值易耗品 | 水下机器人穿线密封胶 | 400米耐压密封胶 / 赠推杆和5个胶管 | 1 | 75.00 | 75.00 | 2026-08-28 | VIOCEAN海目云海洋科技企业店 | CPI-SEAL-005 | 直接使用 | 专用穿线密封胶匹配灵敏性较高；商家耐压宣称及材料相容性需试验核验
ZC-20260828-003 | 设备及装置 | 项目组件 | ROV纯铅配重块 | 约200g/块 | 5 | 23.00 | 115.00 | 2026-08-28 | VIOCEAN海目云海洋科技企业店 | CPI-MECH-008 | 部分使用 | 已购5块、合计约1kg；缺少可移动安装结构与防腐处理说明，暂不冲减配重组件待购量
ZC-20260828-004 | 工具器具 | 通用工具 | 1:1 AB胶枪 | AB胶枪 / 1比1 | 1 | 45.00 | 45.00 | 2026-08-28 | VIOCEAN海目云海洋科技企业店 | CPI-SEAL-005 | 通用工具不纳入 | 用于密封胶施工；属外部装配工具，不计入机器人本体BOM
ZC-20260828-005 | 设备及装置 | 可周转资产 | 水下机器人ROV探照灯 | 6500K / ArduSub脉宽控制 / 100°光束角 | 1 | 299.00 | 299.00 | 2026-08-28 | EXOCEAN拓洲智能 | CPI-LIGHT-001 | 直接使用 | 与现有同类探照灯合计两盏，覆盖第一版需求；电压、PWM及密封性需到货测试
ZC-20260828-006 | 材料耗材 | 低值易耗品 | M5×16 304不锈钢杯头内六角螺钉 | M5×16 / 50个 | 1 | 5.36 | 5.36 | 2026-08-28 | 伯瑞特官方旗舰店 |  | 待BOM确认 | 当前BOM主要单列M3紧固件；M5×16的安装位置和需求量待结构图确认
ZC-20260830-001 | 材料耗材 | 低值易耗品 | 绿林高纯度焊锡丝 | 锡含量63% / 0.8mm / 50g / 自带松香 | 2 | 15.80 | 31.60 | 2026-08-30 | 绿林官方旗舰店 | CPI-CONS-013 | 部分使用 | 新购为63%含锡焊丝，不等同BOM要求的无铅低温锡丝；可作调试用料，暂不增加合规库存数
ZC-20260901-001 | 工具器具 | 可周转资产 | 15件套充电式电动螺丝刀 | 15件套 / 充电式 / 手持电钻螺丝刀 | 1 | 27.84 | 27.84 | 2026-09-01 | 鲸选坐标超市（西丽店） |  | 通用工具不纳入 | 用于外部装配和维护，属于可周转工具，不计入单台机器人本体BOM
ZC-20260901-002 | 材料耗材 | 低值易耗品 | 75%酒精消毒湿巾 | 带盖大包 / 75%酒精 | 1 | 5.97 | 5.97 | 2026-09-01 | 鲸选坐标超市（西丽店） |  | 非本体采购不纳入 | 用于作业清洁和消毒，不安装在机器人本体，不计入单台机器人BOM
ZC-20260901-003 | 材料耗材 | 低值易耗品 | 公牛PVC电工绝缘胶带 | 黑色 / 9米/卷 / 阻燃耐低温 | 1 | 3.02 | 3.02 | 2026-09-01 | 鲸选坐标超市（西丽店） | CPI-CONS-012 | 装配耗材 | 作为辅助绝缘和线束整理耗材；现有同类已覆盖主BOM需求，不改变需求数量
ZC-20260901-004 | 材料耗材 | 低值易耗品 | 鹰牌水磨砂纸 | 150目 | 5 | 1.194 | 5.97 | 2026-09-01 | 鲸选坐标超市（西丽店） |  | 装配耗材 | 用于表面打磨和装配前处理；当前BOM未单列该耗材，不改变主BOM需求
ZC-20260902-001 | 电子元器件 | 项目组件 | XT60并联转接头 | XT60 两母一公 | 1 | 10.40 | 10.40 | 2026-09-02 | 亿恒电子888 | CPI-POWER-001 | 部分使用 | 作为XT60支路并联转接附件；主BOM分电板已由现有设备覆盖，接入前需确认极性和载流能力
ZC-20260902-002 | 电子元器件 | 项目组件 | XT90公母头延长转接线 | XT90公头转母头 / 10号线 / 30cm | 1 | 15.70 | 15.70 | 2026-09-02 | 亿恒电子888 | CPI-POWER-001 | 部分使用 | 作为XT90输入侧延长转接附件；用途关联分电板供电链路，不改变主BOM需求数量
ZC-20260902-003 | 电子元器件 | 项目组件 | 4S平衡充电延长线（第1条） | 4S（5线）/ 22AWG / 公转母 / 10cm | 1 | 2.90 | 2.90 | 2026-09-02 | 尼莱电子 |  | 非本体采购不纳入 | 用于4S电池平衡充电延长，属于充电附件，不计入单台机器人本体BOM
ZC-20260902-004 | 电子元器件 | 项目组件 | 4S平衡充电延长线（第2条） | 4S（5线）/ 22AWG / 公转母 / 10cm | 1 | 3.40 | 3.40 | 2026-09-02 | 尼莱电子 |  | 非本体采购不纳入 | 用于4S电池平衡充电延长；截图规格文字相同，按订单第2条单列，不计入单台机器人本体BOM
ZC-20260902-005 | 设备及装置 | 可周转资产 | IMAX B6AC 80W平衡充电器 | B6AC+XT90线 / 内置电源 / 80W | 1 | 89.99 | 89.99 | 2026-09-02 | 星星模型配件 |  | 通用工具不纳入 | 用于动力电池充电与调试，属于外部可周转设备，不计入单台机器人本体BOM

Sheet: 待确认项
CavePI 工程待确认项
这些条目会影响最终采购数量或安全性。当前假设仅用于BOM占位，不代表完成设计验证。
编号 | 分类 | 确认事项 | 当前假设 | 需要确认/验证 | 对BOM的影响 | 建议动作
CHK-001 | 耐压结构 | 160×300 mm、壁厚5 mm亚克力舱体的30 m耐压能力 | 尺寸已确认，耐压结论未确认 | 材料牌号、加工缺口、端盖边界条件及压力试验 | 可能改变筒体壁厚、端盖和锁紧结构 | 完成结构计算，并分级进行负压检漏与水压试验
CHK-002 | 耐压结构 | 端盖材料、厚度和连接方式 | 端盖2件 | 端盖材料、厚度、密封槽、压环/螺栓方案 | 决定端盖、压环、密封圈和紧固件规格 | 先完成端盖剖面和密封槽工程图
CHK-003 | 机械结构 | 框架尺寸、材料与推进器布局 | 四推进器、4自由度布局 | 结构图、安装孔位、浮心与重心 | 决定框架、支架、安装板及紧固件数量 | 完成装配CAD后更新装配耗材数量
CHK-004 | 水密布线 | 主穿舱件数量与口径 | 调试版5个、第一版8个、升级增加4个 | 逐根线缆的线径、电流、屏蔽与可拆卸需求 | 可能改变穿舱件、灌封胶和端盖开孔数量 | 建立线缆/穿舱接口表后锁定
CHK-005 | 电源 | 第一版动力电池容量与尺寸 | 4S 20-30Ah建议区间，目标1-2 h | 静态负载、巡航推进器电流、峰值电流、可用放电深度和舱内容积 | 决定电池、保险丝、线径与续航 | 完成整机功耗实测后计算容量并做热测试
CHK-006 | 浮力稳定 | 浮力材料与配重 | 目标微正浮力 | 整机干重、排水体积、浮心/重心位置 | 决定浮力块和配重数量及位置 | 整机装配后水池称重、配平与失电上浮测试
CHK-007 | 热管理 | 密闭舱内温升 | 树莓派优先被动散热 | 持续高负载1-2 h温升及电池热状态 | 可能增加导热件或调整计算平台位置 | 在密闭状态下做最大负载热测试
CHK-008 | 后续升级 | Jetson Nano和树莓派5具体版本 | 各1套 | 算力、功耗、接口和供货情况 | 影响电源容量、散热和舱内空间 | 完成算法算力测试后选型
CHK-009 | 后续升级 | 摄像头与光学窗口 | 前视、下视各1套 | 低照度性能、视场角、接口、窗口材料和畸变 | 影响舱体开孔、窗口和照明布置 | 先做水下成像与视场验证
CHK-010 | 后续升级 | 定位与建图传感器组合 | DVL、水声定位、成像声呐均列为选配 | 任务范围、精度、预算、功耗和安装空间 | 可能显著增加预算、重量和水密接口 | 先确定定位建图指标，再在选配件中取舍

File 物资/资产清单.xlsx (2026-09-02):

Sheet: 资产清单
资产清单
口径：纳入全部实物采购；运费、快递费和打包费单列于“未纳入资产”。存放地点、使用部门、责任人、使用状态及盘点状态请按实际补录。
资产条目数 |  |  | 96 |  | 实物采购数量 |  |  | 137 |  | 资产原值（元） |  |  | 9311.88
资产编号 | 管理类别 | 资产属性 | 资产名称 | 规格/型号 | 采购数量 | 单价（元） | 资产原值（元） | 购置日期 | 供应商/店铺 | 存放地点 | 使用部门 | 责任人 | 使用状态 | 盘点状态 | 来源分表 | 来源行号 | 采购备注
ZC-20260713-001 | 材料耗材 | 低值易耗品 | 绿林高纯度锡丝 | 自带松香/无铅低温 | 1 | 15.80 | 15.80 | 2026-07-13 | 绿林官方旗舰店 |  |  |  |  |  | 2026-07-13 | 4
ZC-20260713-002 | 材料耗材 | 低值易耗品 | 绿林烙铁头（刀头） | 通用936内热式 | 4 | 2.61 | 10.44 | 2026-07-13 | 绿林官方旗舰店 |  |  |  |  |  | 2026-07-13 | 5 | 原备注：14
ZC-20260713-003 | 工具器具 | 可周转资产 | 绿林电烙铁 | 60W可调温 | 1 | 25.80 | 25.80 | 2026-07-13 | 绿林官方旗舰店 |  |  |  |  |  | 2026-07-13 | 6
ZC-20260713-004 | 设备及装置 | 可周转资产 | 80W航模平衡充电器 | BT2.0第3版/支持1-6S | 1 | 149.90 | 149.90 | 2026-07-13 | 零轴电子科技企业店 |  |  |  |  |  | 2026-07-13 | 7 | 原备注：14
ZC-20260713-005 | 电子元器件 | 项目组件 | XT60 Hub分电板 | 一拖四扩展板/集线器 | 1 | 29.90 | 29.90 | 2026-07-13 | Autoro电子科技 |  |  |  |  |  | 2026-07-13 | 8 | 原备注：14
ZC-20260713-006 | 电子元器件 | 项目组件 | 博立方电源模块 | 支持2S-12S/带5.3V BEC/XT60 | 1 | 71.24 | 71.24 | 2026-07-13 | 博立方无人机企业店 |  |  |  |  |  | 2026-07-13 | 9 | 原备注：14
ZC-20260713-007 | 设备及装置 | 可周转资产 | 航模锂电池 | 14.8V 5000mAh 长条 | 1 | 74.82 | 74.82 | 2026-07-13 | 阳河科技 |  |  |  |  |  | 2026-07-13 | 10 | 5000mAh仅做调试使用，后续再选择大容量电池
ZC-20260713-008 | 仪器仪表 | 可周转资产 | 水下测距传感器 | 3米量程/8-800cm | 1 | 103.00 | 103.00 | 2026-07-13 | 深圳市电应普科技 |  |  |  |  |  | 2026-07-13 | 11 | 原备注：14
ZC-20260713-009 | 设备及装置 | 可周转资产 | TS60水下推进器 | 蓝黑500/12V | 1 | 189.00 | 189.00 | 2026-07-13 | 淘宝店铺 |  |  |  |  |  | 2026-07-13 | 12 | 先买一个做调试，后续需购足4个
ZC-20260713-010 | 仪器仪表 | 可周转资产 | 深度计 | MS5837-30Ba TB30 | 1 | 199.00 | 199.00 | 2026-07-13 | 淘宝店铺 |  |  |  |  |  | 2026-07-13 | 13
ZC-20260713-011 | 设备及装置 | 可周转资产 | 双向无刷电机电调 | 35A水下动力 | 1 | 95.00 | 95.00 | 2026-07-13 | 淘宝店铺 |  |  |  |  |  | 2026-07-13 | 14 | 先买一个做调试，后续需购足4个
ZC-20260713-012 | 设备及装置 | 可周转资产 | 树莓派4B开发板 | 4B/4G基础套餐 | 1 | 1511.21 | 1511.21 | 2026-07-13 | 淘宝店铺 |  |  |  |  |  | 2026-07-13 | 15
ZC-20260713-013 | 设备及装置 | 可周转资产 | Pixhawk 2.4.8飞控 | 无GPS/刷好Ardusub | 1 | 599.00 | 599.00 | 2026-07-13 | 初将科技 |  |  |  |  |  | 2026-07-13 | 16
ZC-20260721-001 | 工具器具 | 可周转资产 | 德力西小螺丝刀套装 | 45合一/S2+CR-V材质 | 1 | 27.70 | 27.70 | 2026-07-21 | 德力西手动工具旗舰店 |  |  |  |  |  | 2026-07-21 | 4 | 优惠后实付价27.70元；订单页显示实付款0元；订单号3313250403681008294
ZC-20260722-001 | 材料耗材 | 低值易耗品 | 单头六角铜柱 | M3×12+3/50支 | 1 | 8.41 | 8.41 | 2026-07-22 | 固万基官方旗舰店 |  |  |  |  |  | 2026-07-22 | 4 | 确认订单优惠后价格
ZC-20260722-002 | 材料耗材 | 低值易耗品 | 单头六角铜柱 | M3×6+3/100支 | 1 | 10.93 | 10.93 | 2026-07-22 | 固万基官方旗舰店 |  |  |  |  |  | 2026-07-22 | 5 | 确认订单优惠后价格
ZC-20260722-003 | 材料耗材 | 低值易耗品 | 单头六角铜柱 | M3×15+3/50支 | 1 | 10.93 | 10.93 | 2026-07-22 | 固万基官方旗舰店 |  |  |  |  |  | 2026-07-22 | 6 | 确认订单优惠后价格
ZC-20260722-004 | 材料耗材 | 低值易耗品 | 单头六角铜柱 | M3×20+3/50支 | 1 | 12.46 | 12.46 | 2026-07-22 | 固万基官方旗舰店 |  |  |  |  |  | 2026-07-22 | 7 | 确认订单优惠后价格
ZC-20260722-005 | 材料耗材 | 低值易耗品 | 304不锈钢平垫圈 | M5×8×0.5/200只 | 1 | 4.04 | 4.04 | 2026-07-22 | 固万基官方旗舰店 |  |  |  |  |  | 2026-07-22 | 8 | 确认订单优惠后价格
ZC-20260722-006 | 材料耗材 | 低值易耗品 | 304不锈钢平垫圈 | M4×7×0.5/200只 | 1 | 3.19 | 3.19 | 2026-07-22 | 固万基官方旗舰店 |  |  |  |  |  | 2026-07-22 | 9 | 确认订单优惠后价格
ZC-20260722-007 | 材料耗材 | 低值易耗品 | 304不锈钢平垫圈 | M3×6×0.5/200只 | 1 | 3.19 | 3.19 | 2026-07-22 | 固万基官方旗舰店 |  |  |  |  |  | 2026-07-22 | 10 | 确认订单优惠后价格
ZC-20260722-008 | 材料耗材 | 低值易耗品 | 单头六角铜柱 | M3×100+6/5支 | 1 | 9.46 | 9.46 | 2026-07-22 | 固万基官方旗舰店 |  |  |  |  |  | 2026-07-22 | 11 | 确认订单优惠后价格
ZC-20260722-009 | 材料耗材 | 低值易耗品 | 单头六角铜柱 | M3×24+3/20支 | 1 | 7.06 | 7.06 | 2026-07-22 | 固万基官方旗舰店 |  |  |  |  |  | 2026-07-22 | 12 | 确认订单优惠后价格
ZC-20260722-010 | 仪器仪表 | 可周转资产 | 数字万用表 | 多功能智能防烧/标配+备用电池 | 1 | 18.60 | 18.60 | 2026-07-22 | 嘉华仪器仪表批发中心 |  |  |  |  |  | 2026-07-22 | 13 | 确认订单优惠后价格
ZC-20260722-011 | 材料耗材 | 低值易耗品 | 304不锈钢六角螺母 | M5/50个 | 1 | 2.26 | 2.26 | 2026-07-22 | 楚卫旗舰店 |  |  |  |  |  | 2026-07-22 | 14 | 确认订单优惠后价格
ZC-20260722-012 | 材料耗材 | 低值易耗品 | 304不锈钢六角螺母 | M4/100个 | 1 | 3.18 | 3.18 | 2026-07-22 | 楚卫旗舰店 |  |  |  |  |  | 2026-07-22 | 15 | 确认订单优惠后价格
ZC-20260722-013 | 材料耗材 | 低值易耗品 | 304不锈钢六角螺母 | M3/100个 | 1 | 2.09 | 2.09 | 2026-07-22 | 楚卫旗舰店 |  |  |  |  |  | 2026-07-22 | 16 | 确认订单优惠后价格
ZC-20260722-014 | 材料耗材 | 低值易耗品 | 304内六角螺钉 | M3×12/100个 | 1 | 2.60 | 2.60 | 2026-07-22 | 楚卫旗舰店 |  |  |  |  |  | 2026-07-22 | 17 | 确认订单优惠后价格
ZC-20260722-015 | 材料耗材 | 低值易耗品 | 304十字圆头螺钉 | M5×12/50个 | 1 | 4.78 | 4.78 | 2026-07-22 | 佰瑞特官方旗舰店 |  |  |  |  |  | 2026-07-22 | 18 | 确认订单优惠后价格
ZC-20260722-016 | 材料耗材 | 低值易耗品 | 304十字圆头螺钉 | M4×12/50个 | 1 | 2.75 | 2.75 | 2026-07-22 | 佰瑞特官方旗舰店 |  |  |  |  |  | 2026-07-22 | 19 | 确认订单优惠后价格
ZC-20260722-017 | 材料耗材 | 低值易耗品 | 304十字圆头螺钉 | M4×10/100个 | 1 | 4.95 | 4.95 | 2026-07-22 | 佰瑞特官方旗舰店 |  |  |  |  |  | 2026-07-22 | 20 | 确认订单优惠后价格
ZC-20260722-018 | 材料耗材 | 低值易耗品 | 304十字圆头螺钉 | M3×10/100个 | 1 | 2.96 | 2.96 | 2026-07-22 | 佰瑞特官方旗舰店 |  |  |  |  |  | 2026-07-22 | 21 | 确认订单优惠后价格
ZC-20260722-019 | 材料耗材 | 低值易耗品 | 304十字圆头螺钉 | M3×6/100个 | 1 | 2.34 | 2.34 | 2026-07-22 | 佰瑞特官方旗舰店 |  |  |  |  |  | 2026-07-22 | 22 | 确认订单优惠后价格
ZC-20260722-020 | 工具器具 | 可周转资产 | 接线端子压线钳 | HSC8 6-4A/0.25-10mm²/四边形 | 1 | 16.90 | 16.90 | 2026-07-22 | 德力西聚优品专卖店 |  |  |  |  |  | 2026-07-22 | 23 | 确认订单优惠后价格
ZC-20260722-021 | 材料耗材 | 低值易耗品 | 管型端子套装 | VE1508针形铜鼻子/8种规格/1200只 | 1 | 17.82 | 17.82 | 2026-07-22 | UTL尤提乐岚行专卖店 |  |  |  |  |  | 2026-07-22 | 24 | 确认订单优惠后价格
ZC-20260722-022 | 材料耗材 | 低值易耗品 | 迷你接线端子连接器 | H3802-15A-03/3位/白色 | 5 | 4.98 | 24.90 | 2026-07-22 | elinkerelectric旗舰店 |  |  |  |  |  | 2026-07-22 | 25 | 确认订单优惠后价格
ZC-20260724-001 | 设备及装置 | 可周转资产 | 12V锂电池充电器 | 12-12.6V/1A-2A/5.5mm圆孔/线长1米 | 1 | 12.50 | 12.50 | 2026-07-24 | 浩可充电器实力工厂 |  |  |  |  |  | 2026-07-24 | 4 | 确认订单优惠后价格
ZC-20260724-002 | 设备及装置 | 可周转资产 | 公牛六位总控插座 | B9330/全长1.8米 | 1 | 38.00 | 38.00 | 2026-07-24 | 公牛多德专卖店 |  |  |  |  |  | 2026-07-24 | 5 | 确认订单补贴后价格
ZC-20260728-002 | 材料耗材 | 低值易耗品 | 单头六角铜柱 | M3*24+6（20支） | 1 | 8.01 | 8.01 | 2026-07-28 | 固万基官方旗舰店 |  |  |  |  |  | 2026-07-28 | 5 | 优惠后价；先用后付
ZC-20260728-003 | 材料耗材 | 低值易耗品 | 单头六角铜柱 | M3*37+6（20支） | 1 | 14.40 | 14.40 | 2026-07-28 | 固万基官方旗舰店 |  |  |  |  |  | 2026-07-28 | 6 | 优惠后价；先用后付
ZC-20260728-004 | 工具器具 | 可周转资产 | 钳子三件套 | 8寸工业级套装（老虎钳+斜嘴钳+尖嘴钳） | 1 | 26.27 | 26.27 | 2026-07-28 | 天天特卖工厂 |  |  |  |  |  | 2026-07-28 | 7 | 补贴后价；先用后付
ZC-20260728-005 | 电子元器件 | 项目组件 | XT60公母插头 | XT60公头12AWG，3.4平方，30厘米，5条 | 1 | 26.00 | 26.00 | 2026-07-28 | 创未良品电子科技有限公司 |  |  |  |  |  | 2026-07-28 | 8 | 优惠后价；先用后付
ZC-20260729-001 | 电子元器件 | 项目组件 | DC-DC降压模块 | QS-1205CBUM-10A / DC-DC 5V 10A | 1 | 17.60 | 17.60 | 2026-07-29 | 深圳市优信电子科技有限公司 |  |  |  |  |  | 2026-07-29 | 4 | 实付款17.60元
ZC-20260729-002 | 设备及装置 | 可周转资产 | 水下机器人ROV探照灯 | Ardusub脉宽控制 / 光束角100° / 2500流明 / 8-30V宽压 / PWM驱动 | 1 | 306.00 | 306.00 | 2026-07-29 | EXOCEAN拓洲智能 |  |  |  |  |  | 2026-07-29 | 5 | 商品标价294元；实付款306元（含运费12元）
ZC-20260729-003 | 电子元器件 | 项目组件 | USB转RS232/TTL通讯模块 | Y804（USB转TTL）/ 通讯电平5V | 1 | 16.40 | 16.40 | 2026-07-29 | 雨伽量旗舰店 |  |  |  |  |  | 2026-07-29 | 6 | 实付款16.40元
ZC-20260803-001 | 材料耗材 | 低值易耗品 | 304不锈钢十字圆头机牙螺钉 | M3*22 / 100个 | 1 | 5.15 | 5.15 | 2026-08-03 | 佰瑞特官方旗舰店 |  |  |  |  |  | 2026-08-03 | 4 | 先用后付；确认收货后应付5.15元
ZC-20260803-002 | 材料耗材 | 低值易耗品 | 304不锈钢十字圆头机牙螺钉 | M3*20 / 100个 | 1 | 4.87 | 4.87 | 2026-08-03 | 佰瑞特官方旗舰店 |  |  |  |  |  | 2026-08-03 | 5 | 先用后付；确认收货后应付4.87元
ZC-20260803-003 | 材料耗材 | 低值易耗品 | 304不锈钢防松锁紧螺母 | M3 / 304材质 / 40个 | 1 | 1.94 | 1.94 | 2026-08-03 | 固万基五金科技 |  |  |  |  |  | 2026-08-03 | 6 | 先用后付；确认收货后应付1.94元
ZC-20260807-001 | 设备及装置 | 可周转资产 | ROV电源板开关天启大电流控制器 | 5V/12V输出 / 板载大电流MOS开关 | 1 | 249.00 | 249.00 | 2026-08-07 | 店铺名未显示 |  |  |  |  |  | 2026-08-07 | 4 | 包邮；截图未显示完整店铺名
ZC-20260807-002 | 设备及装置 | 可周转资产 | 海目云水下机器人大深水旋钮开关 | M10开关 | 1 | 93.58 | 93.58 | 2026-08-07 | VIOCEAN海目云海洋科技企业店 |  |  |  |  |  | 2026-08-07 | 5 | 补贴后价格
ZC-20260807-003 | 工具器具 | 可周转资产 | 得力办公家用不锈钢美工剪刀 | 办公家用剪刀 | 1 | 8.00 | 8.00 | 2026-08-07 | 得力文具品牌旗舰店 |  |  |  |  |  | 2026-08-07 | 6 | 文具订单商品
ZC-20260807-004 | 工具器具 | 可周转资产 | 小鱼儿有机玻璃透明直尺 | 塑料透明尺 | 1 | 2.00 | 2.00 | 2026-08-07 | 得力文具品牌旗舰店 |  |  |  |  |  | 2026-08-07 | 7 | 文具订单商品
ZC-20260807-005 | 工具器具 | 可周转资产 | 得力小号迷你美工刀 | 拆快递迷你美工刀 | 1 | 3.00 | 3.00 | 2026-08-07 | 得力文具品牌旗舰店 |  |  |  |  |  | 2026-08-07 | 8 | 文具订单商品
ZC-20260807-006 | 材料耗材 | 低值易耗品 | 电工绝缘胶带 | PVC阻燃防水绝缘胶带 | 2 | 2.50 | 5.00 | 2026-08-07 | 得力文具品牌旗舰店 |  |  |  |  |  | 2026-08-07 | 9 | 2卷合计5元
ZC-20260810-001 | 电子元器件 | 项目组件 | 纯铜加粗0.5平方5A大电流Type-C公单头线 | 0.3m / Type-C公单 / 黑色 | 1 | 4.98 | 4.98 | 2026-08-10 | 邵深源线材工厂批发店 |  |  |  |  |  | 2026-08-10 | 4 | 先用后付；订单号3316184510600008294
ZC-20260814-001 | 工具器具 | 可周转资产 | 热熔胶枪 | 7mm胶棒适用 / 不含胶棒 | 1 | 20.20 | 20.20 | 2026-08-14 | 咚宜佳超市（大学城店） |  |  |  |  |  | 2026-08-14 | 4 | 实付价
ZC-20260814-002 | 材料耗材 | 低值易耗品 | 热熔胶棒 | 7mm / 1条装 | 10 | 0.43 | 4.30 | 2026-08-14 | 咚宜佳超市（大学城店） |  |  |  |  |  | 2026-08-14 | 5 | 10条合计4.30元
ZC-20260817-001 | 材料耗材 | 低值易耗品 | 美标特软硅胶线 | 28AWG / 黑色 / 10米/卷 | 1 | 8.49 | 8.49 | 2026-08-17 | skygod旗舰店 |  |  |  |  |  | 2026-08-17 | 4 | 优惠后价；先用后付
ZC-20260817-002 | 材料耗材 | 低值易耗品 | 美标特软硅胶线 | 28AWG / 红色 / 10米/卷 | 1 | 8.49 | 8.49 | 2026-08-17 | skygod旗舰店 |  |  |  |  |  | 2026-08-17 | 5 | 优惠后价；先用后付
ZC-20260817-003 | 电子元器件 | 项目组件 | XT60母对母延长线 | 0.2m / XT60母对母 / 10AWG（5.3mm²） | 1 | 15.88 | 15.88 | 2026-08-17 | 安捷达线束 |  |  |  |  |  | 2026-08-17 | 6 | 免密支付；包邮
ZC-20260817-004 | 材料耗材 | 低值易耗品 | 六角铜柱机箱螺丝钉 | M3×20+6 / 20颗 | 1 | 5.66 | 5.66 | 2026-08-17 | 固万基官方旗舰店 |  |  |  |  |  | 2026-08-17 | 7 | 优惠后价；先用后付
ZC-20260817-005 | 材料耗材 | 低值易耗品 | 304不锈钢杯头内六角螺钉 | M3×16 / 100个 | 1 | 3.63 | 3.63 | 2026-08-17 | 楚卫旗舰店 |  |  |  |  |  | 2026-08-17 | 8 | 先用后付；当前实付0元，预计自动扣款3.63元；订单号3316977480159071850
ZC-20260818-001 | 材料耗材 | 低值易耗品 | M10密封舱实心螺栓 | 铝制密封螺丝 / M10 | 4 | 25.00 | 100.00 | 2026-08-18 | 天启ROV97 |  |  |  |  |  | 2026-08-18 | 4 | 包邮；与M10穿线螺丝同单合计370元
ZC-20260818-002 | 材料耗材 | 低值易耗品 | M10穿线螺丝 | 银色 / 不锈钢 / M10 | 9 | 30.00 | 270.00 | 2026-08-18 | 天启ROV97 |  |  |  |  |  | 2026-08-18 | 5 | 包邮；与密封舱实心螺栓同单合计370元
ZC-20260818-003 | 设备及装置 | 可周转资产 | TS60水下推进器 | 蓝黑500KV正桨 / 推荐12V使用 | 3 | 189.00 | 567.00 | 2026-08-18 | 天启ROV97 |  |  |  |  |  | 2026-08-18 | 6 | 包邮；与电调、密封舱同单；优惠后合计1997元
ZC-20260818-004 | 设备及装置 | 可周转资产 | 35A双向无刷电调 | 35A / 双向 / 水下动力 | 3 | 95.00 | 285.00 | 2026-08-18 | 天启ROV97 |  |  |  |  |  | 2026-08-18 | 7 | 包邮；与推进器、密封舱同单；优惠后合计1997元
ZC-20260818-005 | 设备及装置 | 可周转资产 | 海目云水下机器人密封舱 | 外径160mm×300mm / 亚克力圆管+半球罩+法兰+金属圈+端盖+密封圈+硅脂+配套螺丝 | 1 | 1145.00 | 1145.00 | 2026-08-18 | VIOCEAN海目云海洋科技企业店 |  |  |  |  |  | 2026-08-18 | 8 | 优惠后价1145元（标价1150元）；整套含亚克力圆管、半球罩、法兰、金属圈、端盖、密封圈、硅脂和配套螺丝；与推进器、电调同单合计1997元
ZC-20260818-006 | 电子元器件 | 项目组件 | 八合一大电流分电板 | 输入XT90 / 输出XT60 / 焊好出货 | 1 | 97.50 | 97.50 | 2026-08-18 | 梁小二模型 |  |  |  |  |  | 2026-08-18 | 9 | 商品97.50元；运费5.00元另列；实付款102.50元
ZC-20260818-007 | 电子元器件 | 项目组件 | XT90H黑色母头带线 | XT90H黑母头 / 8AWG（8.29mm²）/ 红黑线 / 10cm | 1 | 10.12 | 10.12 | 2026-08-18 | 阳光模型上海DIY（截图店名截断） |  |  |  |  |  | 2026-08-18 | 10 | 先用后付；确认收货后应付10.12元
ZC-20260818-008 | 电子元器件 | 项目组件 | XT90H黄色公头带线 | XT90H黄公头 / 8AWG（8.29mm²）/ 红黑线 / 10cm | 1 | 11.11 | 11.11 | 2026-08-18 | 阳光模型上海DIY（截图店名截断） |  |  |  |  |  | 2026-08-18 | 11 | 先用后付；确认收货后应付11.11元
ZC-20260825-001 | 工具器具 | 通用工具 | 密封舱气密性测试套装 | 真空枪+宝塔气嘴 / 工具箱套装 | 1 | 245.00 | 245.00 | 2026-08-25 | VIOCEAN海目云海洋科技企业店 |  |  |  |  |  | 2026-08-25 | 4 | 实付款245元；图1、2为同一订单，去重登记
ZC-20260825-002 | 材料耗材 | 低值易耗品 | 黑色快干AB环氧树脂胶 | 黑色快干款 / 5分钟初固 / 两支装 / 送工具 | 1 | 15.10 | 15.10 | 2026-08-25 | 固万旗舰店 |  |  |  |  |  | 2026-08-25 | 5 | 先用后付；确认收货后应付15.10元
ZC-20260825-003 | 设备及装置 | 项目组件 | 4S6P水下机器人锂电池 | 14.8V / 18Ah / 4S6P | 1 | 1552.00 | 1552.00 | 2026-08-25 | 仙藤电池 |  |  |  |  |  | 2026-08-25 | 6 | 实付款1552.00元
ZC-20260826-001 | 材料耗材 | 低值易耗品 | M2.5 304不锈钢六角螺母 | M2.5 / 100个 | 1 | 2.46 | 2.46 | 2026-08-26 | 金超官方旗舰店 |  |  |  |  |  | 2026-08-26 | 4 | 先用后付；确认收货后应付2.46元
ZC-20260826-002 | 材料耗材 | 低值易耗品 | M2.5尼龙平垫片 | M2.5×5×1mm / 200个 | 1 | 4.00 | 4.00 | 2026-08-26 | 品诺塑胶垫圈供应商 |  |  |  |  |  | 2026-08-26 | 5 | 先用后付；确认收货后应付4.00元
ZC-20260826-003 | 材料耗材 | 低值易耗品 | M2.5×8 304不锈钢十字圆头机牙螺钉 | M2.5×8 / 200个 | 1 | 5.71 | 5.71 | 2026-08-26 | 伯瑞特官方旗舰店 |  |  |  |  |  | 2026-08-26 | 6 | 先用后付；确认收货后应付5.71元
ZC-20260826-004 | 材料耗材 | 低值易耗品 | M2.5×6 304不锈钢十字圆头机牙螺钉 | M2.5×6 / 200个 | 1 | 5.07 | 5.07 | 2026-08-26 | 伯瑞特官方旗舰店 |  |  |  |  |  | 2026-08-26 | 7 | 先用后付；确认收货后应付5.07元
ZC-20260826-005 | 材料耗材 | 低值易耗品 | M2.5×10 304不锈钢十字圆头机牙螺钉 | M2.5×10 / 200个 | 1 | 6.19 | 6.19 | 2026-08-26 | 伯瑞特官方旗舰店 |  |  |  |  |  | 2026-08-26 | 8 | 先用后付；确认收货后应付6.19元
ZC-20260826-006 | 材料耗材 | 低值易耗品 | 黑色自锁式尼龙扎带 | 4×150mm / 黑色 / 500根 | 1 | 17.39 | 17.39 | 2026-08-26 | 伯瑞特官方旗舰店 |  |  |  |  |  | 2026-08-26 | 9 | 先用后付；确认收货后应付17.39元
ZC-20260826-007 | 材料耗材 | 低值易耗品 | M3×20 304不锈钢杯头内六角螺钉 | M3×20 / 50个 | 1 | 1.12 | 1.12 | 2026-08-26 | 资鑫旗舰店 |  |  |  |  |  | 2026-08-26 | 10 | 先用后付；确认收货后应付1.12元
ZC-20260828-001 | 材料耗材 | 低值易耗品 | ROV专用防水密封硅脂 | 水下密封专用硅脂 | 1 | 49.00 | 49.00 | 2026-08-28 | VIOCEAN海目云海洋科技企业店 |  |  |  |  |  | 2026-08-28 | 4 | 已签收；商品金额49.00元
ZC-20260828-002 | 材料耗材 | 低值易耗品 | 水下机器人穿线密封胶 | 400米耐压密封胶 / 赠推杆和5个胶管 | 1 | 75.00 | 75.00 | 2026-08-28 | VIOCEAN海目云海洋科技企业店 |  |  |  |  |  | 2026-08-28 | 5 | 已签收；商品金额75.00元
ZC-20260828-003 | 设备及装置 | 项目组件 | ROV纯铅配重块 | 约200g/块 | 5 | 23.00 | 115.00 | 2026-08-28 | VIOCEAN海目云海洋科技企业店 |  |  |  |  |  | 2026-08-28 | 6 | 已签收；5块共115.00元
ZC-20260828-004 | 工具器具 | 通用工具 | 1:1 AB胶枪 | AB胶枪 / 1比1 | 1 | 45.00 | 45.00 | 2026-08-28 | VIOCEAN海目云海洋科技企业店 |  |  |  |  |  | 2026-08-28 | 7 | 已签收；商品金额45.00元
ZC-20260828-005 | 设备及装置 | 可周转资产 | 水下机器人ROV探照灯 | 6500K / ArduSub脉宽控制 / 100°光束角 | 1 | 299.00 | 299.00 | 2026-08-28 | EXOCEAN拓洲智能 |  |  |  |  |  | 2026-08-28 | 9 | 商品标价299.00元；实付311.00元，差额12.00元另列
ZC-20260828-006 | 材料耗材 | 低值易耗品 | M5×16 304不锈钢杯头内六角螺钉 | M5×16 / 50个 | 1 | 5.36 | 5.36 | 2026-08-28 | 伯瑞特官方旗舰店 |  |  |  |  |  | 2026-08-28 | 11 | 先用后付；确认收货后应付5.36元
ZC-20260830-001 | 材料耗材 | 低值易耗品 | 绿林高纯度焊锡丝 | 锡含量63% / 0.8mm / 50g / 自带松香 | 2 | 15.80 | 31.60 | 2026-08-30 | 绿林官方旗舰店 |  |  |  |  |  | 2026-08-30 | 4 | 先用后付；确认收货后应付31.60元；63%焊锡不等同BOM要求的无铅低温锡丝
ZC-20260901-001 | 工具器具 | 可周转资产 | 15件套充电式电动螺丝刀 | 15件套 / 充电式 / 手持电钻螺丝刀 | 1 | 27.84 | 27.84 | 2026-09-01 | 鲸选坐标超市（西丽店） |  |  |  |  |  | 2026-09-01 | 4 | 订单已送达；截图实付27.84元
ZC-20260901-002 | 材料耗材 | 低值易耗品 | 75%酒精消毒湿巾 | 带盖大包 / 75%酒精 | 1 | 5.97 | 5.97 | 2026-09-01 | 鲸选坐标超市（西丽店） |  |  |  |  |  | 2026-09-01 | 5 | 订单已送达；截图实付5.97元
ZC-20260901-003 | 材料耗材 | 低值易耗品 | 公牛PVC电工绝缘胶带 | 黑色 / 9米/卷 / 阻燃耐低温 | 1 | 3.02 | 3.02 | 2026-09-01 | 鲸选坐标超市（西丽店） |  |  |  |  |  | 2026-09-01 | 6 | 订单已送达；截图实付3.02元
ZC-20260901-004 | 材料耗材 | 低值易耗品 | 鹰牌水磨砂纸 | 150目 | 5 | 1.194 | 5.97 | 2026-09-01 | 鲸选坐标超市（西丽店） |  |  |  |  |  | 2026-09-01 | 7 | 订单已送达；5张合计5.97元
ZC-20260902-001 | 电子元器件 | 项目组件 | XT60并联转接头 | XT60 两母一公 | 1 | 10.40 | 10.40 | 2026-09-02 | 亿恒电子888 |  |  |  |  |  | 2026-09-02 | 4 | 订单号33163934900009008294；已发货
ZC-20260902-002 | 电子元器件 | 项目组件 | XT90公母头延长转接线 | XT90公头转母头 / 10号线 / 30cm | 1 | 15.70 | 15.70 | 2026-09-02 | 亿恒电子888 |  |  |  |  |  | 2026-09-02 | 5 | 订单号33163934900009008294；已发货
ZC-20260902-003 | 电子元器件 | 项目组件 | 4S平衡充电延长线（第1条） | 4S（5线）/ 22AWG / 公转母 / 10cm | 1 | 2.90 | 2.90 | 2026-09-02 | 尼莱电子 |  |  |  |  |  | 2026-09-02 | 6 | 订单号33163934900009053486；待发货
ZC-20260902-004 | 电子元器件 | 项目组件 | 4S平衡充电延长线（第2条） | 4S（5线）/ 22AWG / 公转母 / 10cm | 1 | 3.40 | 3.40 | 2026-09-02 | 尼莱电子 |  |  |  |  |  | 2026-09-02 | 7 | 截图所示规格文字相同，按订单第2条单列；待发货
ZC-20260902-005 | 设备及装置 | 可周转资产 | IMAX B6AC 80W平衡充电器 | B6AC+XT90线 / 内置电源 / 80W | 1 | 89.99 | 89.99 | 2026-09-02 | 星星模型配件 |  |  |  |  |  | 2026-09-02 | 9 | 订单号33163934900009099495；已发货

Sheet: 分类汇总
资产分类汇总
汇总结果由“资产清单”公式驱动，可随明细维护同步更新。
管理类别 | 条目数 | 采购数量 | 资产原值（元）
材料耗材 | 50 | 83 | 839.44
电子元器件 | 14 | 14 | 333.13
工具器具 | 11 | 11 | 447.71
设备及装置 | 18 | 26 | 7371.00
仪器仪表 | 3 | 3 | 320.60
合计 | 96 | 137 | 9311.88

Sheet: 未纳入资产
未纳入资产项目
以下项目属于运费、快递费或打包费，用于与采购总额勾稽，但不计入实物资产原值。
日期 | 费用名称 | 金额（元） | 供应商/店铺 | 来源分表 | 来源行号 | 采购备注
2026-07-13 | 总运费 | 21.00 |  | 2026-07-13 | 17
2026-07-28 | 顺丰快递费 | 27.00 | 顺丰 | 2026-07-28 | 4 | 今日快递费
2026-08-07 | 运费 | 9.00 | 得力文具品牌旗舰店 | 2026-08-07 | 10 | 商品金额18元；运费9元
2026-08-14 | 打包费 | 1.00 | 咚宜佳超市（大学城店） | 2026-08-14 | 6 | 商品24.50元；打包费1.00元
2026-08-18 | 运费 | 5.00 | 梁小二模型 | 2026-08-18 | 12 | 分电板订单：实付款102.50元=商品97.50元+运费5.00元
2026-08-28 | 运费 | 10.00 | VIOCEAN海目云海洋科技企业店 | 2026-08-28 | 8 | 用户确认：VIOCEAN订单10.00元差额为运费
2026-08-28 | 运费 | 12.00 | EXOCEAN拓洲智能 | 2026-08-28 | 10 | 用户确认：EXOCEAN订单12.00元差额为运费
2026-09-02 | 运费 | 6.00 | 尼莱电子 | 2026-09-02 | 8 | 商品合计6.30元+运费6.00元=实付12.30元
费用合计 |  | 91
勾稽项目 | 金额（元）
实物资产原值 | 9311.88
未纳入费用 | 91.00
勾稽采购总额 | 9402.88
原采购总额 | 9402.88
差额 | 1.818989404e-12

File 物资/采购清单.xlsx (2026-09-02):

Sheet: 2026-07-13
2026-07-13 采购清单
采购日期：2026-07-13
序号 | 商品名称 | 规格/型号 | 数量 | 单价（元） | 金额（元） | 店铺 | 备注
1 | 绿林高纯度锡丝 | 自带松香/无铅低温 | 1 | 15.80 | 15.80 | 绿林官方旗舰店
2 | 绿林烙铁头（刀头） | 通用936内热式 | 4 | 2.61 | 10.44 | 绿林官方旗舰店 | 原备注：14
3 | 绿林电烙铁 | 60W可调温 | 1 | 25.80 | 25.80 | 绿林官方旗舰店
4 | 80W航模平衡充电器 | BT2.0第3版/支持1-6S | 1 | 149.90 | 149.90 | 零轴电子科技企业店 | 原备注：14
5 | XT60 Hub分电板 | 一拖四扩展板/集线器 | 1 | 29.90 | 29.90 | Autoro电子科技 | 原备注：14
6 | 博立方电源模块 | 支持2S-12S/带5.3V BEC/XT60 | 1 | 71.24 | 71.24 | 博立方无人机企业店 | 原备注：14
7 | 航模锂电池 | 14.8V 5000mAh 长条 | 1 | 74.82 | 74.82 | 阳河科技 | 5000mAh仅做调试使用，后续再选择大容量电池
8 | 水下测距传感器 | 3米量程/8-800cm | 1 | 103.00 | 103.00 | 深圳市电应普科技 | 原备注：14
9 | TS60水下推进器 | 蓝黑500/12V | 1 | 189.00 | 189.00 | 淘宝店铺 | 先买一个做调试，后续需购足4个
10 | 深度计 | MS5837-30Ba TB30 | 1 | 199.00 | 199.00 | 淘宝店铺
11 | 双向无刷电机电调 | 35A水下动力 | 1 | 95.00 | 95.00 | 淘宝店铺 | 先买一个做调试，后续需购足4个
12 | 树莓派4B开发板 | 4B/4G基础套餐 | 1 | 1511.21 | 1511.21 | 淘宝店铺
13 | Pixhawk 2.4.8飞控 | 无GPS/刷好Ardusub | 1 | 599.00 | 599.00 | 初将科技
14 | 总运费 |  |  | 21.00 | 21.00
本日合计 |  |  | 16 |  | 3095.11

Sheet: 2026-07-21
2026-07-21 采购清单
采购日期：2026-07-21
序号 | 商品名称 | 规格/型号 | 数量 | 单价（元） | 金额（元） | 店铺 | 备注
1 | 德力西小螺丝刀套装 | 45合一/S2+CR-V材质 | 1 | 27.70 | 27.70 | 德力西手动工具旗舰店 | 优惠后实付价27.70元；订单页显示实付款0元；订单号3313250403681008294
本日合计 |  |  | 1 |  | 27.70

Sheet: 2026-07-22
2026-07-22 采购清单
采购日期：2026-07-22
序号 | 商品名称 | 规格/型号 | 数量 | 单价（元） | 金额（元） | 店铺 | 备注
1 | 单头六角铜柱 | M3×12+3/50支 | 1 | 8.41 | 8.41 | 固万基官方旗舰店 | 确认订单优惠后价格
2 | 单头六角铜柱 | M3×6+3/100支 | 1 | 10.93 | 10.93 | 固万基官方旗舰店 | 确认订单优惠后价格
3 | 单头六角铜柱 | M3×15+3/50支 | 1 | 10.93 | 10.93 | 固万基官方旗舰店 | 确认订单优惠后价格
4 | 单头六角铜柱 | M3×20+3/50支 | 1 | 12.46 | 12.46 | 固万基官方旗舰店 | 确认订单优惠后价格
5 | 304不锈钢平垫圈 | M5×8×0.5/200只 | 1 | 4.04 | 4.04 | 固万基官方旗舰店 | 确认订单优惠后价格
6 | 304不锈钢平垫圈 | M4×7×0.5/200只 | 1 | 3.19 | 3.19 | 固万基官方旗舰店 | 确认订单优惠后价格
7 | 304不锈钢平垫圈 | M3×6×0.5/200只 | 1 | 3.19 | 3.19 | 固万基官方旗舰店 | 确认订单优惠后价格
8 | 单头六角铜柱 | M3×100+6/5支 | 1 | 9.46 | 9.46 | 固万基官方旗舰店 | 确认订单优惠后价格
9 | 单头六角铜柱 | M3×24+3/20支 | 1 | 7.06 | 7.06 | 固万基官方旗舰店 | 确认订单优惠后价格
10 | 数字万用表 | 多功能智能防烧/标配+备用电池 | 1 | 18.60 | 18.60 | 嘉华仪器仪表批发中心 | 确认订单优惠后价格
11 | 304不锈钢六角螺母 | M5/50个 | 1 | 2.26 | 2.26 | 楚卫旗舰店 | 确认订单优惠后价格
12 | 304不锈钢六角螺母 | M4/100个 | 1 | 3.18 | 3.18 | 楚卫旗舰店 | 确认订单优惠后价格
13 | 304不锈钢六角螺母 | M3/100个 | 1 | 2.09 | 2.09 | 楚卫旗舰店 | 确认订单优惠后价格
14 | 304内六角螺钉 | M3×12/100个 | 1 | 2.60 | 2.60 | 楚卫旗舰店 | 确认订单优惠后价格
15 | 304十字圆头螺钉 | M5×12/50个 | 1 | 4.78 | 4.78 | 佰瑞特官方旗舰店 | 确认订单优惠后价格
16 | 304十字圆头螺钉 | M4×12/50个 | 1 | 2.75 | 2.75 | 佰瑞特官方旗舰店 | 确认订单优惠后价格
17 | 304十字圆头螺钉 | M4×10/100个 | 1 | 4.95 | 4.95 | 佰瑞特官方旗舰店 | 确认订单优惠后价格
18 | 304十字圆头螺钉 | M3×10/100个 | 1 | 2.96 | 2.96 | 佰瑞特官方旗舰店 | 确认订单优惠后价格
19 | 304十字圆头螺钉 | M3×6/100个 | 1 | 2.34 | 2.34 | 佰瑞特官方旗舰店 | 确认订单优惠后价格
20 | 接线端子压线钳 | HSC8 6-4A/0.25-10mm²/四边形 | 1 | 16.90 | 16.90 | 德力西聚优品专卖店 | 确认订单优惠后价格
21 | 管型端子套装 | VE1508针形铜鼻子/8种规格/1200只 | 1 | 17.82 | 17.82 | UTL尤提乐岚行专卖店 | 确认订单优惠后价格
22 | 迷你接线端子连接器 | H3802-15A-03/3位/白色 | 5 | 4.98 | 24.90 | elinkerelectric旗舰店 | 确认订单优惠后价格
本日合计 |  |  | 26 |  | 175.80

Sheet: 总计
采购总计
按采购日期汇总；各项数据自动引用对应日期分表
采购日期 | 品类数 | 商品数量 | 采购金额（元） | 备注
2026-07-13 | 13 | 16 | 3095.11 | 详见 2026-07-13 分表
2026-07-21 | 1 | 1 | 27.70 | 详见 2026-07-21 分表
2026-07-22 | 22 | 26 | 175.80 | 详见 2026-07-22 分表
2026-07-24 | 2 | 2 | 50.50 | 详见 2026-07-24 分表
2026-07-28 | 4 | 4 | 101.68 | 详见 2026-07-28 分表
2026-07-29 | 3 | 3 | 340.00 | 详见 2026-07-29 分表
2026-08-03 | 3 | 3 | 11.96 | 详见 2026-08-03 分表
2026-08-07 | 6 | 7 | 369.58 | 详见 2026-08-07 分表
2026-08-10 | 1 | 1 | 4.98 | 详见 2026-08-10 分表
2026-08-14 | 2 | 11 | 25.50 | 详见 2026-08-14 分表
2026-08-17 | 5 | 5 | 42.15 | 详见 2026-08-17 分表
2026-08-18 | 9 | 24 | 2490.73 | 详见 2026-08-18 分表
2026-08-25 | 3 | 3 | 1812.10 | 详见 2026-08-25 分表
2026-08-26 | 7 | 7 | 41.94 | 详见 2026-08-26 分表
2026-08-28 | 8 | 12 | 610.36 | 详见 2026-08-28 分表
2026-08-30 | 1 | 2 | 31.60 | 详见 2026-08-30 分表
2026-09-01 | 4 | 8 | 42.80 | 详见 2026-09-01 分表
2026-09-02 | 6 | 6 | 128.39 | 详见 2026-09-02 分表
总计 | 100 | 141 | 9402.88 | 全部采购记录

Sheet: 2026-07-24
2026-07-24 采购清单
采购日期：2026-07-24
序号 | 商品名称 | 规格/型号 | 数量 | 单价（元） | 金额（元） | 店铺 | 备注
1 | 12V锂电池充电器 | 12-12.6V/1A-2A/5.5mm圆孔/线长1米 | 1 | 12.50 | 12.50 | 浩可充电器实力工厂 | 确认订单优惠后价格
2 | 公牛六位总控插座 | B9330/全长1.8米 | 1 | 38.00 | 38.00 | 公牛多德专卖店 | 确认订单补贴后价格
本日合计 |  |  | 2 |  | 50.50
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

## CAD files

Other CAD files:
CAD_designs v2.0/子装/Clamp for Vertical Thrusters_Mid.SLDASM
CAD_designs v2.0/装配体/装配体2.SLDASM
CAD_designs v2.0/Head/Camera_Fish Eye.SLDASM
CAD_designs v2.0/子装/Clamp for Sonar(with components).SLDASM
CAD_designs v2.0/装配体/HMY-DPC-160300（半球罩+平盖）.SLDASM
CAD_designs v2.0/子装/Battery Mounting_behind Plate(with components).SLDASM
CAD_designs v2.0/子装/Battery Mounting_Right Plate(with components).SLDASM
CAD_designs v2.0/子装/Battery Mounting_front Plate(with components)^装配体2.SLDASM
CAD_designs v2.0/子装/Clamp for Horizontal Thrusters.SLDASM
CAD_designs v2.0/子装/Battery Mounting_Left Plate(with components).SLDASM
CAD_designs v2.0/子装/密封舱1.SLDASM
CAD_designs v2.0/Computational Enclosure/assy-pi-4b-asm.stp
CAD_designs v2.0/Computational Enclosure/Raspberry Pi 5.SLDASM
CAD_designs v2.0/Computational Enclosure/Jetson Nano.SLDASM
CAD_designs v2.0/Computational Enclosure/Mounting Plate_connect_Flange.SLDPRT
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

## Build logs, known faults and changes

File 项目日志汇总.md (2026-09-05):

# AUV 子项目日志汇总

> 本文件由工作日日志汇总任务维护。按日期保留历史记录；同一天重复运行时，应更新对应日期的条目，不重复追加。

## 2026-08-17

**汇总时间：** 2026-08-17 17:54（Asia/Shanghai）

### 总体进展

- 今日有新增或修改的项目日志为 `CAD_designs v2.0/项目日志.md` 和 `电源管理/项目日志.md`。
- 机械结构 v2.0 已完成首轮内部结构 3D 打印件试装，已定位铜柱、水平推进器夹具螺母沉孔和 XT60 接口的装配问题，进入针对性修改与再验证阶段。
- 电源管理新发现水下开关现有线缆长度不足，计划确定延长量后焊接延长，并补充采购 XT60 母对母转接线和延长导线。
- CAD v1.0 今日未发现新日志；以下保留其 2026-08-16 的最新状态，作为后续跟踪基线。

### CAD_designs v2.0（机械结构）

**进展与完成事项**

- 完成内部结构 3D 打印件首轮试装。
- 试装确认了三类需改进项：铜柱螺纹长度、水平推进器夹具螺母安装方式、电源管理板 XT60 接口避让空间。

**问题与风险**

1. 现有 M3 × 20 × 3 铜柱螺纹长度不足，暂时无法满足装配配合。
2. 夹具螺母计划改为电烙铁热压嵌入，但沉孔尺寸与配合公差尚未确定，存在重复打样的可能。
3. XT60 接口与内部结构已确认存在干涉，若避让和布线空间不足，将影响整体装配。

**下一步计划**

1. 购买 M3 × 20 × 6 铜柱，到货后复核螺纹配合与装配稳定性。
2. 设计并打印螺母热压嵌入沉孔测试件，确定尺寸与公差。
3. 修改 XT60 接口周边结构，补足接头安装和线束布线空间。
4. 完成修改后重新 3D 打印并进行新一轮整体试装。

### 电源管理

**进展与完成事项**

- 已形成 14.8 V 4S 电池供电的主方案和备用副方案，明确动力与补光、Pixhawk、树莓派及声呐的基本供电路径。
- 主方案由电源管理板分别为大电流支路、Pixhawk 5 V/3 A 支路和树莓派 5 V/3 A 支路供电；副方案使用 BEC 为 Pixhawk 降压供电。
- 今日完成布线检查，确认水下开关现有线缆长度不足，并列出 XT60 母对母转接线与延长导线的采购需求。

**问题与风险**

1. 后续整机大容量电池拟使用 XT90，而现有电源管理板输入为 XT60，接口兼容方案尚未解决。
2. 机械试装已验证 XT60 接口存在结构干涉，需与机械结构修改联动处理。
3. 大电流支路额定能力、两路 5 V/3 A 供电余量、BEC 稳定性、共地关系及过流/短路/防反接保护尚需系统核对。
4. 水下开关线缆长度不足；焊接延长会引入焊点牢固性、绝缘密封和应力保护风险。

**下一步计划**

1. 根据整机峰值和持续电流校核电源板、分电板、接头及线束额定能力。
2. 核实 Pixhawk/深度计与树莓派/声呐两路 5 V 负载的稳态和瞬态余量。
3. 确定 XT90 至 XT60 的可靠接入或替代电源管理板方案。
4. 结合下一轮机械试装，复核 XT60 接头、线束与插拔空间。
5. 根据实际安装位置和布线路径确定水下开关线缆的延长量，采购所需转接线和导线。
6. 延长后检查焊点、绝缘、密封和应力保护，并完成通断功能及布线试装验证。

### CAD_designs v1.0（最新日志：2026-08-16）

**进展与完成事项**

- 已完成对 CavePI 开源密封舱模型的加工可行性与成本评估。
- 评估结论为该规格难以通过常规商家定制，小批量 CNC 加工法兰和金属垫圈的难度与成本较高，因此现阶段已放弃 v1.0 方案。

**问题与风险**

- v1.0 方案已终止，不建议继续投入定制加工资源；后续工作应避免与 v2.0 模型或采购规格混用。

**下一步计划**

- 无独立后续开发计划；保留文件作为历史方案和选型决策记录。

### 日志读取与纳入范围

- **已纳入：** `CAD_designs v2.0/项目日志.md`、`电源管理/项目日志.md`、`CAD_designs v1.0/项目日志.md`。
- **已扫描但未纳入：** `参考资料` 目录下 6 份历史 `*.build_log.htm`（其中 3 组内容各有 2 份镜像副本）。这些文件均可读，但属于 2018–2023 年参考代码的编译输出，不是当前子项目进展日志。
- **未能读取：** 无。

## 2026-08-18

**汇总时间：** 2026-08-18 17:52（Asia/Shanghai）

### 总体进展

- 今日新增或修改的项目日志为 `CAD_designs v2.0/项目日志.md`、`电源管理/项目日志.md` 和 `物资/项目日志.md`；其中物资管理首次纳入汇总。
- 机械结构 v2.0 已完成水平推进器夹具螺母沉孔建模修改，并取得补光灯、推进器和声呐线缆的实测线径，为外部支撑架线槽优化提供了依据。
- 电源管理已更新至 2.0 单一供电架构，主电源输入及至分电板的大电流输出均由 XT60 调整为 XT90；原 XT90 电池与 XT60 电源板不兼容问题已在方案层面处理。
- 今日登记采购 5 类、共 20 件物资，金额合计 2367 元；近期机械装配和布线所需的 XT60 延长线、M3 × 20+6 铜柱及红黑延长导线也已进入采购清单。
- CAD v1.0 今日未发现新日志；继续保留其 2026-08-16 已放弃方案的状态作为历史基线。

### CAD_designs v2.0（机械结构）

**进展与完成事项**

- 已将 `Clamp for Horizontal Thrusters` 的螺母沉孔修改为直径 6 mm、深度 2.5 mm。
- 已完成外部设备线缆线径测量：补光灯 5 mm、推进器 5 mm、声呐 4 mm。

**问题与风险**

1. 外部支撑架线槽尺寸尚未最终确定，需结合线束数量、布线方式和装配余量确定宽度、深度及出入口尺寸。
2. 螺母沉孔的热压嵌入配合、固定效果和周边结构完整性仍需通过打印实物验证。
3. 电源方案 2.0 已将主接口调整为尺寸更大的 XT90；机械结构不能继续仅按原 XT60 干涉结论修改，需与电源选型同步复核接头、线束弯曲和插拔空间。
4. M3 × 20+6 铜柱虽已纳入采购清单，但到货前仍无法完成螺纹配合与装配稳定性验证。

**下一步计划**

1. 打印修改后的水平推进器夹具，进行螺母热压嵌入试验。
2. 确定外部支撑架线槽尺寸并修改相关零件，随后打印试装，验证线束通过性和固定效果。
3. 根据最终电源管理模块和 XT90 接口实物尺寸修改接口周边结构，并完成整体试装。
4. 铜柱到货后复核螺纹配合和装配稳定性。

### 电源管理

**进展与完成事项**

- 电源管理方案已更新至 2.0 版，取消原主、副方案并采用单一供电架构。
- 14.8 V 4S 电池至电源管理模块的输入、以及电源管理模块至分电板的大电流输出均改用 XT90；Pixhawk、树莓派、深度计、声呐、补光灯和电调的供电与控制逻辑基本保持不变。
- 原“大容量电池 XT90 输出与电源管理板 XT60 输入不兼容”问题已在方案层面处理。

**问题与风险**

1. 实际电源管理模块的型号、XT90 接口配置、持续/峰值电流和散热能力尚未完成硬件确认。
2. 方案图中至分电板的连接为 XT90，但分电板仍标注为 8 路 XT60，实际输入接口、转接线需求或更换方案尚待确认。
3. 两路 5 V/3 A 输出的稳态与瞬态供电余量，以及主干线、分支、接头、分电板和线束的额定能力仍需核算和验证。
4. XT90 尺寸大于 XT60，可能增加结构避让、线束弯曲半径和插拔空间需求。
5. 水下开关线缆长度不足的问题仍未解决；拟采购的 28AWG 导线需先按实际回路电流和原线线径确认适用性，焊接后还需验证绝缘、密封和应力保护。

**下一步计划**

1. 完成电源管理模块和分电板的选型/实物接口确认，明确是否需要 XT90 转接或更换分电板。
2. 重新核算推进器、补光灯及其他负载的持续和峰值电流，核对所有供电器件与线束额定能力。
3. 实测验证两路 5 V/3 A 输出的稳态和瞬态负载能力。
4. 与机械结构联动完成 XT90 周边结构修改和 3D 打印整体试装。
5. 确认水下开关回路的延长导线规格后实施焊接，并完成通断、绝缘、密封及布线验证。

### 物资管理

**进展与完成事项**

- 今日登记 M10 密封舱实心螺栓 4 件、M10 穿线螺丝 9 件、TS60 水下推进器 3 台、35 A 双向无刷电调 3 个、海目云 160 mm × 300 mm 密封舱 1 套。
- 今日共登记 5 类、20 件物资，金额合计 2367 元。
- 与近期问题关联的 XT60 母对母延长线、M3 × 20+6 铜柱，以及 28AWG 红黑硅胶线已在 2026-08-17 采购清单中登记。

**问题与风险**

1. 采购登记不代表已完成到货验收；数量、规格、外观和功能仍待实物核对。
2. 密封舱、实心螺栓和穿线螺丝需验证接口及装配配合，并在正式使用前完成密封性测试。
3. 推进器与电调需核对型号、接口和电气参数，并进行单套配对调试。
4. 28AWG 延长导线是否适合水下开关回路尚未确认，存在载流能力或与原线线径不匹配的风险。

**下一步计划**

1. 到货后按采购清单逐项验收并记录异常。
2. 完成密封舱及其螺栓、穿线螺丝的装配配合和密封性验证。
3. 完成推进器与电调的单套配对调试。
4. 验证 XT60 延长线方向与布线空间、铜柱螺纹配合，以及延长导线的电气适用性。

### 日志读取与纳入范围

- **今日有更新并纳入：** `CAD_designs v2.0/项目日志.md`、`电源管理/项目日志.md`、`物资/项目日志.md`。
- **已检查但无新内容：** `CAD_designs v1.0/项目日志.md`；其最新状态见 2026-08-17 汇总，不在今日条目重复展开。
- **已扫描但未纳入：** `参考资料` 目录下 6 份历史 `*.build_log.htm`（3 组内容各有 2 份镜像副本）。这些文件均可读，但属于 2018–2023 年参考代码编译输出，不是当前子项目进展日志。
- **未能读取：** 无。

## 2026-08-19

**汇总时间：** 2026-08-19 17:25（Asia/Shanghai）

### 总体进展

- 今日新增或修改的项目日志为 `CAD_designs v2.0/项目日志.md`。
- 机械结构 v2.0 已依据补光灯 5 mm、推进器 5 mm、声呐 4 mm 的实测线径，完成 `Clamp for Horizontal Thrusters` 等外部支撑架线槽建模文件的适配修改。
- 其他子项目日志今日未发现新内容；继续沿用各自最近一次汇总状态，不在今日条目重复展开。

### CAD_designs v2.0（机械结构）

**进展与完成事项**

- 已完成 `Clamp for Horizontal Thrusters` 等外部支撑架线槽建模文件的修改。
- 线槽结构已按补光灯 5 mm、推进器 5 mm、声呐 4 mm 的实测线径进行适配。

**问题与风险**

1. 修改后的零件尚未完成实体打印和真实线缆走线试装，线槽宽度、深度、出入口及转弯处的通过性仍待验证。
2. 线束固定效果与装配余量尚未确认，实装时可能出现线缆挤压、过度弯折或脱出线槽的问题。

**下一步计划**

1. 打印修改后的外部支撑架零件。
2. 使用实际补光灯、推进器和声呐线缆进行走线试装，验证线槽各处的通过性。
3. 检查线束固定效果和装配余量，并排查挤压、过度弯折及脱槽现象。

### 日志读取与纳入范围

- **今日有更新并纳入：** `CAD_designs v2.0/项目日志.md`。
- **已检查但无新内容：** `电源管理/项目日志.md`、`物资/项目日志.md`、`CAD_designs v1.0/项目日志.md`；其最新状态见此前汇总，不在今日条目重复展开。
- **已扫描但未纳入：** `参考资料` 目录下 6 份历史 `*.build_log.htm`（3 组内容各有 2 份镜像副本）。这些文件均可读，但属于 2018–2023 年参考代码的编译输出，不是当前子项目进展日志。
- **未能读取：** 无。

## 2026-08-20

**汇总时间：** 2026-08-20 18:23（Asia/Shanghai）

### 总体进展

- 今日未发现新增或修改的子项目日志，因此没有新的进展、完成事项、问题或风险以及下一步计划可供提炼。
- 各子项目继续沿用最近一次汇总状态：`CAD_designs v2.0` 见 2026-08-19，`电源管理` 与 `物资` 见 2026-08-18，`CAD_designs v1.0` 见 2026-08-17；本条目不重复展开历史内容。

### 日志读取与纳入范围

- **今日有更新并纳入：** 无。
- **已检查但无新内容：** `CAD_designs v2.0/项目日志.md`、`电源管理/项目日志.md`、`物资/项目日志.md`、`CAD_designs v1.0/项目日志.md`。
- **已扫描但未纳入：** `参考资料` 目录下 6 份历史 `*.build_log.htm`（3 组内容各有 2 份镜像副本）。这些文件均可读，但属于 2018–2023 年参考代码的编译输出，不是当前子项目进展日志。
- **未能读取：** 无。

## 2026-08-21

**汇总时间：** 2026-08-21 17:43（Asia/Shanghai）

### 总体进展

- 今日新增或修改的项目日志为 `电源管理/项目日志.md`。
- 电源管理板输入端和输出端均已焊接 XT90 延长线，电源管理方案 2.0 的 XT90 主干接口已由方案落实为实物改造。
- 电源管理板输出端已连接一拖八分电板，基本连接与供电功能测试正常，当前连接方案具备继续装配验证的条件。
- 其他子项目日志今日未发现新内容；继续沿用各自最近一次汇总状态，不在今日条目重复展开。

### 电源管理

**进展与完成事项**

- 已在电源管理板输入端和输出端分别焊接 XT90 延长线，完成 XT90 主干接口改造。
- 已将电源管理板输出端连接至一拖八分电板，并完成基本连接与供电功能测试。
- 测试结果正常，现阶段连接方案可用。

**问题与风险**

1. 本次仅完成基本功能验证，尚未覆盖整机实际负载、持续运行及瞬态工况，供电稳定性和带载能力仍待验证。
2. 一拖八分电板的安装位置和固定方式尚未确定，需兼顾密封舱内部空间、支撑架及其他电子设备布置。
3. XT90 主干线、各路 XT60 分支线及接头若预留空间不足，可能产生插拔不便、线束干涉或弯折半径不足的问题。
4. 整机装配后仍需关注焊点受力、绝缘防护和散热条件，避免振动或线束拉扯影响连接可靠性。

**下一步计划**

1. 结合密封舱、支撑架和其他电子设备确定一拖八分电板的安装位置。
2. 设计分电板固定方式，并为 XT90 主干线、XT60 分支线和接头插拔预留足够空间。
3. 完成安装后复查线束干涉、焊点应力、绝缘防护和散热条件，并再次通电测试。
4. 在整机装配条件下开展带载与稳定性测试，验证持续运行和实际工况下的供电可靠性。

### 日志读取与纳入范围

- **今日有更新并纳入：** `电源管理/项目日志.md`。
- **已检查但无新内容：** `CAD_designs v2.0/项目日志.md`、`物资/项目日志.md`、`CAD_designs v1.0/项目日志.md`；其最新状态分别见 2026-08-19、2026-08-18 和 2026-08-17 汇总，不在今日条目重复展开。
- **已扫描但未纳入：** `参考资料` 目录下 6 份历史 `*.build_log.htm`（3 组内容各有 2 份镜像副本）。这些文件均可读，但属于 2018–2023 年参考代码的编译输出，不是当前子项目进展日志。
- **未能读取：** 无。

## 2026-08-24

**汇总时间：** 2026-08-24 17:51（Asia/Shanghai）

### 总体进展

- 今日新增或修改的项目日志为 `CAD_designs v2.0/项目日志.md`。
- 机械结构 v2.0 先完成了增加内部支撑层、用于放置一拖八分电板的建模方案；评估发现密封舱高度空间偏紧后，已将该方案以提交 `93ef902` 暂存并推送，再将建模文件恢复至 2026-08-21 基线提交 `2271a56`。
- 回退后已形成更节省高度的新布局：电源管理板改装至 `Battery Mounting_front Plate`，原 `Mounting Plate_PowerModule` 修改孔位后用于安装一拖八分电板。当前建模装配观感合理，但尚未完成实物验证。
- 其他子项目日志今日未发现新内容；继续沿用各自最近一次汇总状态，不在今日条目重复展开。

### CAD_designs v2.0（机械结构）

**进展与完成事项**

- 已完成内部支撑结构加层方案的建模，并同步调整相关安装板、支撑件、紧固件及装配体。
- 已将加层方案作为可恢复的暂存版本提交并推送至 GitHub（提交 `93ef902`），随后恢复至 2026-08-21 基线提交 `2271a56`，保留本日工作日志。
- 回退后重新设计板卡布局：电源管理板安装于 `Battery Mounting_front Plate`，修改 `Mounting Plate_PowerModule` 孔位以安装一拖八分电板，不再额外增加支撑层。

**问题与风险**

1. 加层方案会挤占密封舱内部高度，增加设备布置、线束弯曲与插拔、整体装配和维护难度，当前不作为 v2.0 的继续迭代基础。
2. 新布局目前仅完成建模评估，电源管理板和分电板的安装孔位、紧固件配合、固定稳定性及实际空间余量尚未验证。
3. XT90 主干线、各路 XT60 分支线、接头插拔和线束弯曲空间可能与周边支撑结构或其他电子设备发生干涉。
4. 单板试装通过也不能替代密封舱内部整体装配验证；仍需确认新布局在整机条件下的可装配性与可维护性。

**下一步计划**

1. 打印新版 `Battery Mounting_front Plate` 和修改孔位后的 `Mounting Plate_PowerModule`。
2. 分别试装电源管理板与一拖八分电板，检查孔位、紧固件配合和板卡固定稳定性。
3. 重点验证 XT90 主干线、XT60 分支线、接头插拔与线束弯曲空间，并排查与周边结构及电子设备的干涉。
4. 完成单板试装后进行密封舱内部整体装配验证，再决定是否将该布局作为 v2.0 正式结构方案。

### 日志读取与纳入范围

- **今日有更新并纳入：** `CAD_designs v2.0/项目日志.md`。
- **已检查但无新内容：** `电源管理/项目日志.md`、`物资/项目日志.md`、`CAD_designs v1.0/项目日志.md`；其最新状态分别见 2026-08-21、2026-08-18 和 2026-08-17 汇总，不在今日条目重复展开。
- **已扫描但未纳入：** `参考资料` 目录下 6 份历史 `*.build_log.htm`（3 组内容各有 2 份镜像副本）。这些文件均可读，但属于 2018–2023 年参考代码编译输出，不是当前子项目进展日志。
- **未能读取：** 无。

## 2026-08-25

**汇总时间：** 2026-08-25 17:53（Asia/Shanghai）

### 总体进展

- 今日未发现新增或修改的子项目日志，因此没有新的进展、完成事项、问题或风险以及下一步计划可供提炼。
- 各子项目继续沿用最近一次汇总状态：`CAD_designs v2.0` 见 2026-08-24，`电源管理` 见 2026-08-21，`物资` 见 2026-08-18，`CAD_designs v1.0` 见 2026-08-17；本条目不重复展开历史内容。
- `CAD_designs v2.0` 目录今日出现的 SolidWorks 临时锁文件不是项目日志，未据此推断或纳入项目进展。

### 日志读取与纳入范围

- **今日有更新并纳入：** 无。
- **已检查但无新内容：** `CAD_designs v2.0/项目日志.md`、`电源管理/项目日志.md`、`物资/项目日志.md`、`CAD_designs v1.0/项目日志.md`。
- **已扫描但未纳入：** `参考资料` 目录下 6 份历史 `*.build_log.htm`（3 组内容各有 2 份镜像副本）。这些文件均可读，但属于 2018–2023 年参考代码编译输出，不是当前子项目进展日志。
- **未能读取：** 无。

## 2026-08-26

**汇总时间：** 2026-08-26 18:56（Asia/Shanghai）

### 总体进展

- 今日新增或修改的项目日志为 `CAD_designs v2.0/项目日志.md` 和 `物资/项目日志.md`。
- 近两日整机装配继续推进；除补光灯、电池、树莓派和声呐外，其余部件已基本完成装配。
- 内部支撑架现采用一端与法兰螺纹配合、另一端不连接法兰的一体抽拉式方案。当前布局紧凑，舱内无明显松动，并有利于后续设备安装、接线与维护。
- 两端均与法兰螺纹配合的方案因无法完全配合且显著增加内部接线和装配难度，已停止采用。
- `Clamp for Sonar` 已按新选型配重块重新建模并进入 3D 打印阶段；但配重块尚未同步至采购、资产和 BOM 台账。
- 今日登记 7 类紧固与线束物资，合计 41.94 元；资产清单与采购清单的金额勾稽差额为 0。
- 电源管理和 CAD v1.0 日志今日未发现新内容；继续沿用各自最近一次汇总状态，不在今日条目重复展开。

### CAD_designs v2.0（机械结构）

**进展与完成事项**

- 除补光灯、电池、树莓派和声呐外，整机其余部件已基本完成装配。
- 已完成一端法兰螺纹配合的一体抽拉式内部支撑架试装；当前固定效果基本可接受，且支撑架可整体抽出，便于安装、布线和维护。
- 已通过实物试装否决两端法兰螺纹配合方案，避免继续投入不利于装配的结构路线。
- 已根据新选型配重块重新建模并优化 `Clamp for Sonar`，相关零件正在 3D 打印。

**问题与风险**

1. 补光灯、电池、树莓派和声呐尚未安装；现有空间和固定效果尚不能代表设备齐全后的最终状态，仍可能出现布线或结构干涉。
2. 推进器线缆过长，需要按最终路径修剪；若预留量不当或重新接线质量不足，可能影响装配维护、导通、绝缘和固定可靠性。
3. 环氧树脂 AB 胶型号及灌胶工艺尚未确定，材料相容性、固化效果、粘接和水密性能均需验证。
4. 整机配重尚未设计，需待设备全部安装后依据实际重量、浮力、重心和浮心确定，否则可能影响浮沉状态与水下姿态。
5. 新版 `Clamp for Sonar` 尚未完成实物试装，夹具尺寸、孔位、紧固空间、线缆通过性、受力稳定性及与声呐、配重块和周边结构的干涉仍待验证。

**下一步计划**

1. 安装补光灯、电池、树莓派和声呐，设备齐全后复查内部空间、支撑稳定性与线束干涉。
2. 根据最终推进器安装位置和布线路径确定线缆保留长度，预留装配、弯曲及维护余量后修剪并重新接线，随后检查导通、绝缘和固定情况。
3. 按灌胶位置、被粘材质、固化条件和水下需求完成环氧树脂 AB 胶选型及工艺验证，并在整机下水前独立开展水密测试。
4. 完成全部设备安装后进行整机重量、浮力、重心和浮心评估，确定配重质量、位置及固定方式，再通过静水试验调整浮沉状态与姿态。
5. 打印完成后使用新选型配重块试装 `Clamp for Sonar`，检查尺寸、孔位、固定效果、结构干涉、紧固空间、线缆通过性和受力稳定性，并据结果继续调整模型。

### 物资

**进展与完成事项**

- 今日登记 M2.5 螺母、尼龙垫片、M2.5 × 6/8/10 螺钉、4 × 150 mm 黑色尼龙扎带和 M3 × 20 杯头内六角螺钉，共 7 类、7 个采购批次，金额合计 41.94 元。
- `资产清单.xlsx` 已同步至 80 个资产条目、112 个实物采购数量，资产原值合计 8526.73 元。
- 采购清单累计 81 类、113 个表内商品数量，采购总额 8589.73 元；扣除 63 元运费、快递费和打包费后，与实物资产金额勾稽差额为 0。
- 尼龙扎带已匹配 BOM 中“尼龙扎带与线束固定座”条目；M3 × 20 杯头螺钉作为现有同长度十字圆头螺钉的替代件或备件管理。

**问题与风险**

1. 线束固定座尚未登记，尼龙扎带对应 BOM 条目仍为“部分已有”，且扎带的耐潮和老化性能尚未验证。
2. 今日登记的 M2.5 螺母、垫片及三种长度螺钉尚未明确对应装配位置，实际需求量和材料适用性待确认。
3. 机械结构采用的新选型配重块尚未出现在采购清单和资产清单中，BOM“可调配重组件”仍为“待选型”，存在结构选型与物资台账不同步风险。

**下一步计划**

1. 结合结构图确认 M2.5 紧固件的具体用途、需求数量和材料适用性，并验证尼龙扎带的耐潮、老化及线束固定效果。
2. 待新版声呐夹具打印试装确认后，补充配重块的规格、数量、价格、供应来源和采购状态，并同步更新采购清单、资产清单及 BOM 状态。

### 日志读取与纳入范围

- **今日有更新并纳入：** `CAD_designs v2.0/项目日志.md`、`物资/项目日志.md`。
- **已检查但无新内容：** `电源管理/项目日志.md`、`CAD_designs v1.0/项目日志.md`；其最新状态分别见 2026-08-21 和 2026-08-17 汇总，不在今日条目重复展开。
- **已扫描但未纳入：** `参考资料` 目录下 6 份历史 `*.build_log.htm`（3 组内容各有 2 份镜像副本）。这些文件均可读，但属于 2018–2023 年参考代码编译输出，不是当前子项目进展日志。
- **未能读取：** 无。

## 2026-08-27

**汇总时间：** 2026-08-27 17:51（Asia/Shanghai）

### 总体进展

- 今日未发现新增或修改的子项目日志，因此没有新的进展、完成事项、问题或风险以及下一步计划可供提炼。
- 各子项目继续沿用最近一次汇总状态：`CAD_designs v2.0` 和 `物资` 见 2026-08-26，`电源管理` 见 2026-08-21，`CAD_designs v1.0` 见 2026-08-17；本条目不重复展开历史内容。
- 工作区今日存在若干 SolidWorks 零件与装配体文件改动，但这些文件不是项目日志，未据此推断或纳入项目进展。

### 日志读取与纳入范围

- **今日有更新并纳入：** 无。
- **已检查但无新内容：** `CAD_designs v2.0/项目日志.md`、`电源管理/项目日志.md`、`物资/项目日志.md`、`CAD_designs v1.0/项目日志.md`。
- **已扫描但未纳入：** `参考资料` 目录下 6 份历史 `*.build_log.htm`（3 组内容各有 2 份镜像副本）。这些文件均可读，但属于 2018–2023 年参考代码的编译输出，不是当前子项目进展日志。
- **未能读取：** 无。

## 2026-08-29

**汇总时间：** 2026-08-29 14:24（Asia/Shanghai）

### 总体进展

- 今日未发现新增或修改的子项目日志，因此没有新的进展、完成事项、问题或风险以及下一步计划可供提炼。
- 各子项目继续沿用最近一次汇总状态：`CAD_designs v2.0` 和 `物资` 见 2026-08-26，`电源管理` 见 2026-08-21，`CAD_designs v1.0` 见 2026-08-17；本条目不重复展开历史内容。
- 上次汇总后存在 SolidWorks 零件与装配体文件变更，但这些文件不是项目日志，未据此推断或纳入项目进展。

### 日志读取与纳入范围

- **今日有更新并纳入：** 无。
- **已检查但无新内容：** `CAD_designs v2.0/项目日志.md`、`电源管理/项目日志.md`、`物资/项目日志.md`、`CAD_designs v1.0/项目日志.md`。
- **已扫描但未纳入：** `参考资料` 目录下 6 份历史 `*.build_log.htm`（3 组内容各有 2 份镜像副本）。这些文件均可读，但属于 2018–2023 年参考代码的编译输出，不是当前子项目进展日志。
- **未能读取：** 无。

## 2026-09-01

**汇总时间：** 2026-09-01 17:51（Asia/Shanghai）

### 总体进展

- 今日检测到 `CAD_designs v2.0` 项目日志新增 2026-08-31 工作记录：已完成穿线螺栓封灌处理及整机组装，并对组装后的密封舱开展两次气密性测试。
- 首次抽气时真空度无法稳定保持，泡沫水检查确认泄漏位于穿线螺栓线缆周边；该处封灌不充分且已开裂，初步判断为胶体完全固化前线缆移动造成裂缝。
- 二次灌胶修补并待胶体凝固后，复测抽至约 15 inHg 并保压 15 分钟，仪表读数未下降，当前气密性表现良好。
- 其余子项目沿用最近一次汇总状态：`物资` 见 2026-08-26，`电源管理` 见 2026-08-21，`CAD_designs v1.0` 见 2026-08-17；本条目不重复展开历史内容。

### 问题、风险与下一步

- 后续穿线螺栓灌胶时需充分填充线缆周边间隙，并在完全固化前固定线缆，避免移动、拉扯或弯折导致封灌层再次开裂。
- 本次结果为负压气密性验证，仍需在正式下水前复查灌胶部位的固化状态和外观，并结合后续装配情况再次进行整机气密性及水密性验证。

### 日志读取与纳入范围

- **今日有更新并纳入：** `CAD_designs v2.0/项目日志.md`（新增 2026-08-31 工作记录）。
- **已检查但无新内容：** `电源管理/项目日志.md`、`物资/项目日志.md`、`CAD_designs v1.0/项目日志.md`。
- **已变更但不作为日志纳入：** `物资` 目录下 3 份 `*.xlsx` 台账及其临时文件、工作区中的 SolidWorks 零件与装配体变更；它们不是项目日志，未据此推断进展。
- **已扫描但未纳入：** `参考资料` 目录下 6 份历史 `*.build_log.htm`（3 组内容各有 2 份镜像副本）。这些文件均可读，但属于 2018–2023 年参考代码的编译输出，不是当前子项目进展日志。
- **未能读取：** 无。

## 2026-09-02

**汇总时间：** 2026-09-02 17:58（Asia/Shanghai）

### 总体进展

- 今日新增或修改的项目日志为 `CAD_designs v2.0/项目日志.md`。
- 昨日整机气密复测再次出现真空度明显下降，已对穿线螺栓线缆周边重新灌胶；本次先用 1500 目砂纸粗化线皮，再用 75% 酒精片清洁，并固定线缆静置过夜固化。
- 今日将真空度抽至 15 inHg 后保压 15 分钟，读数轻微下降但保持在 14～15 inHg，现阶段判定气密性合格。
- 随后完成头部、尾部分别浸水 20 分钟的浅水水密测试；舱内指示纸巾保持干燥，未发现明显进水迹象。
- 针对现有结构未预留便捷外部充电接口的问题，已准备需拆卸半球罩的临时充电方案，并提出使用 7 Pin 航空防水插头引出主充电线与 5 Pin 平衡充线的免拆卸方案。
- 其余子项目日志今日未发现新内容：`物资` 见 2026-08-26，`电源管理` 见 2026-08-21，`CAD_designs v1.0` 见 2026-08-17；本条目不重复展开历史内容。

### CAD_designs v2.0（机械结构与整机）

**进展与完成事项**

- 完成穿线螺栓线缆周边第三次密封整改，增加线皮打磨粗化、酒精清洁、线缆固定和过夜固化步骤。
- 完成整改后的负压气密性测试：15 inHg 起始真空度下保压 15 分钟，读数维持在 14～15 inHg。
- 完成当前场地条件下的分段浅水水密测试：头部、尾部各浸水 20 分钟，舱内纸巾均保持干燥。
- 形成两条电池充电路径：近期使用 XT90 一拖二与主线、平衡充延长线的临时方案；长期拟采用 7 Pin 航空防水插头实现免拆卸充电。

**问题与风险**

1. 气密测试仍有轻微读数下降，且此前曾出现复测不稳定；当前结论只适用于本次 15 分钟测试条件，密封长期稳定性仍需继续观察。
2. 小型水缸无法使整机同时完全浸没，头尾分段各 20 分钟的结果仅属初步验证，不能替代更长时间、完整浸没的整机水密测试。
3. 临时充电方案每次需要拆装半球罩，可能扰动端盖和密封圈；若系统侧未可靠断电，或 XT90 主线、5 Pin 平衡充延长线存在极性、线序、线径或绝缘错误，将带来充电与设备安全风险。
4. 7 Pin 航空插头方案尚未确认主充电端子的额定载流能力、防反接与防误插设计、安装开孔和固定方式、灌封工艺及结构干涉；新增舱体接口也会引入新的潜在泄漏点。

**下一步计划**

1. 更换尺寸更大的水池，使整机完全浸没并延长测试时间，完成更严谨的整机水密性验证。
2. 使用临时方案前确认整机系统断电，并逐项核对 XT90 与平衡充延长线的极性、逐针线序、线径、绝缘和系统侧隔离，充电后重新检查端盖、密封圈和密封状态。
3. 根据实际充电电流完成 7 Pin 航空防水插头选型，设计防反接、防误插和防水盖，并确认舱体或端盖上的安装位置、开孔、固定、灌封及周边干涉。
4. 免拆卸充电接口完成后，验证充电功能、线序和温升，并重新开展整机气密性及完整水密性测试。

### 日志读取与纳入范围

- **今日有更新并纳入：** `CAD_designs v2.0/项目日志.md`（新增 2026-09-02 工作记录）。
- **已检查但无新内容：** `电源管理/项目日志.md`、`物资/项目日志.md`、`CAD_designs v1.0/项目日志.md`。
- **已变更但不作为日志纳入：** `物资` 目录下 3 份 `*.xlsx` 台账、工作区中的 SolidWorks 零件与装配体，以及 `outputs` 和 `SESSION_STATE.md`；这些不是子项目源日志，未据此推断进展。
- **已扫描但未纳入：** `参考资料` 目录下 6 份历史 `*.build_log.htm`（3 组内容各有 2 份镜像副本）。这些文件均可读，但属于 2018–2023 年参考代码编译输出，不是当前子项目进展日志。
- **未能读取：** 无。

## 2026-09-04

**汇总时间：** 2026-09-04 11:11（Asia/Shanghai）

### 总体进展

- 今日未发现新增或修改的子项目日志，因此没有新的进展、完成事项、问题或风险以及下一步计划可供提炼。
- 各子项目继续沿用最近一次汇总状态：`CAD_designs v2.0` 见 2026-09-02，`物资` 见 2026-08-26，`电源管理` 见 2026-08-21，`CAD_designs v1.0` 见 2026-08-17；本条目不重复展开历史内容。
- 工作区中存在 SolidWorks 零件与装配体、`outputs` 和 `SESSION_STATE.md` 等非日志文件变化；这些文件不是子项目源日志，未据此推断或纳入项目进展。

### 日志读取与纳入范围

- **今日有更新并纳入：** 无。
- **已检查但无新内容：** `CAD_designs v2.0/项目日志.md`、`电源管理/项目日志.md`、`物资/项目日志.md`、`CAD_designs v1.0/项目日志.md`。
- **已扫描但未纳入：** `参考资料` 目录下 6 份历史 `*.build_log.htm`（3 组内容各有 2 份镜像副本）。这些文件均可读，但属于 2018–2023 年参考代码编译输出，不是当前子项目进展日志。
- **未能读取：** 无。

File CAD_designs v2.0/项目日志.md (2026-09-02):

# AUV 机械结构 v2.0 项目日志

## 2026-08-16 项目回顾

### 当前进展

目前密封舱拟采用海目云 160 × 300 版本，装配图中的内部支撑架等结构已根据该密封舱完成相应的建模调整。现阶段正在对内部支撑架进行 3D 打印，待打印完成后将通过试装验证各部件之间是否存在干涉。

### 后续计划与验证项

1. 完成内部支撑架 3D 打印件的试装，检查结构干涉情况。
2. 完成上述验证后，进行密封舱的购买与整体装配。

## 2026-08-17 工作日志

### 当前进展

内部结构 3D 打印件已完成试装。试装过程中发现了铜柱规格、水平推进器夹具的螺母安装方式，以及电源管理板 XT60 接口结构干涉等问题，当前需根据试装结果进行针对性修改。

### 存在问题与处理计划

1. **铜柱螺纹长度不足**
   - 现有 M3 × 20 × 3 铜柱的螺纹长度不足，无法满足当前装配配合要求。
   - 需另行购买 M3 × 20 × 6 铜柱，到货后重新验证螺纹配合与装配稳定性。

2. **Clamp for Horizontal Thrusters 螺母沉孔需优化**
   - 现有螺母沉孔的结构与安装方式需要调整。
   - 拟改为使用电烙铁将螺母预先热压嵌入沉孔并固定的形式。沉孔尺寸已确定为直径 6 mm、深度 2.5 mm，后续需通过打印与热压嵌入试验验证实际配合效果。

3. **电源管理板 XT60 接口干涉**
   - 试装后确认电源管理板的 XT60 接口与现有内部结构存在干涉。
   - 需对相关安装结构和接口避让空间进行修改优化，完成后重新打印并试装验证。

### 下一步工作

1. 购买 M3 × 20 × 6 铜柱并复核装配效果。
2. 按直径 6 mm、深度 2.5 mm 修改螺母沉孔模型，并通过打印测试件验证螺母热压嵌入后的配合与固定效果。
3. 修改 XT60 接口周边结构，为接头和线束预留足够的安装及布线空间。
4. 完成上述修改后进行新一轮 3D 打印与整体试装。

## 2026-08-18 工作日志

### 完成事项

Clamp for Horizontal Thrusters 的螺母沉孔已按直径 6 mm、深度 2.5 mm 完成建模修改。

已完成外部设备线缆线径测量，实测结果如下：

- 补光灯线径：5 mm。
- 推进器线径：5 mm。
- 声呐线径：4 mm。

### 待优化事项

Clamp for Horizontal Thrusters 等外部支撑架的线槽尺寸尚未最终确定。目前已取得补光灯、推进器和声呐线缆的实测线径，后续需结合线束数量、布线方式及必要的装配余量，确认线槽的宽度、深度和出入口尺寸，并对相关零件模型进行修改优化。

### 后续验证

1. 打印修改后的 Clamp for Horizontal Thrusters 零件。
2. 使用电烙铁将螺母热压嵌入沉孔，验证尺寸配合、固定效果及周边结构完整性。
3. 完成线槽尺寸修改后，通过打印试装验证线束通过性与固定效果。

## 2026-08-19 工作日志

### 完成事项

Clamp for Horizontal Thrusters 等外部支撑架的线槽建模文件已完成修改。本次修改以已测得的补光灯线径 5 mm、推进器线径 5 mm 和声呐线径 4 mm 为基础，对相关线槽结构进行了适配调整。

### 后续验证

1. 打印修改后的外部支撑架零件。
2. 使用实际补光灯、推进器和声呐线缆进行走线试装，验证线槽宽度、深度、出入口及转弯处的通过性。
3. 检查线束固定效果、装配余量以及线缆是否存在挤压、过度弯折或脱出线槽的情况。

## 2026-08-24 工作日志

### 完成事项

今日对密封舱内部支撑结构进行了重新建模，并在原有支撑结构基础上增加一层，用于放置一拖八分电板。相关安装板、支撑件、紧固件及装配体模型已完成相应调整。

### 方案评估

完成加层建模后发现，新增层会使密封舱内部高度空间略显拥挤，可能增加后续设备布置、线束弯曲与插拔、整体装配及维护的难度。因此，当前不直接将该方案作为 v2.0 的继续迭代基础。

### 方案决策与版本管理

1. 将“内部支撑结构加层放置分电板”的建模方案作为暂存版本提交并推送至 GitHub，保留后续重新评估或恢复的可能。
2. 完成暂存版本保存后，将 `CAD_designs v2.0` 建模文件恢复至 2026-08-24 之前的版本，继续寻找占用高度更小的分电板放置方案。
3. 回退后应重新检查分电板可用放置区域、XT90 主干线及各路 XT60 分支线的布线空间，再确定下一版结构方案。

### GitHub 版本操作结果

1. 加层放置分电板的建模方案已以提交 `93ef902`（暂存内部支撑加层分电板方案）推送至 GitHub。
2. 当前 `CAD_designs v2.0` 建模文件已恢复至今日之前的基线提交 `2271a56`（2026-08-21），本日工作日志继续保留。
3. 后续如需重新评估加层方案，可从提交 `93ef902` 恢复相关建模文件。

### 回退后的新布局方案

在恢复 v2.0 基线建模文件后，重新设计了电源管理板与一拖八分电板的安装布局：

1. 将电源管理板改为安装在 `Battery Mounting_front Plate` 上。
2. 对原本用于安装电源管理板的 `Mounting Plate_PowerModule` 进行孔位修改，使其改用于安装一拖八分电板。
3. 新方案不再通过增加支撑层放置分电板，可减少对密封舱内部高度空间的额外占用。

当前新版建模的整体布局观感较为合理，初步认为具备继续验证的价值。但现阶段结论仅基于建模装配效果，实际孔位配合、空间余量和线束布置情况仍需通过 3D 打印与实物装配确认。

### 后续验证

1. 打印新版 `Battery Mounting_front Plate` 和修改孔位后的 `Mounting Plate_PowerModule`。
2. 分别试装电源管理板与一拖八分电板，检查安装孔位、紧固件配合和板卡固定稳定性。
3. 重点验证 XT90 主干线、各路 XT60 分支线、接头插拔和线束弯曲所需空间，确认与周边支撑结构及其他电子设备无干涉。
4. 完成单板试装后进行密封舱内部整体装配验证，再决定是否将该布局作为 v2.0 的正式结构方案。

## 2026-08-26 工作日志

### 整机装配进展

近两日对整机进行了进一步装配。目前除补光灯、电池、树莓派和声呐尚未安装外，其余部件已基本完成装配。

### 当前内部支撑方案

今日采用内部支撑架一体抽拉式设计与外部亚克力圆筒密封舱进行装配：

1. 内部支撑架的一端与法兰进行螺纹配合，另一端不与法兰连接。
2. 完成装配后，内部布局整体较为紧凑，支撑架在密封舱内没有明显松动，当前的固定效果基本可接受。
3. 一体抽拉式方案可相对简化内部接线与整体装配过程，方便后续抽出支撑架进行设备安装、布线和维护。

### 已放弃方案

昨日曾尝试将内部支撑架两端均与法兰进行螺纹配合。实际试装发现，该方案仍无法使支撑架与两端法兰完全配合，同时会显著增加内部接线和装配难度。综合考虑结构配合与可装配性，已放弃两端法兰螺纹配合方案，改用当前一端配合的一体抽拉式设计。

### 当前问题与后续任务

1. **补齐未安装设备**
   - 后续需完成补光灯、电池、树莓派和声呐的安装，并在设备齐全后重新检查内部空间、固定稳定性与布线干涉。

2. **推进器线缆过长**
   - 当前推进器线缆长度过长，需根据最终安装位置和布线路径确定保留长度后进行修剪。
   - 修剪前需预留合理的装配、弯曲与维护余量；修剪和重新接线后需检查导通、绝缘与固定情况。

3. **环氧树脂 AB 胶选型与灌胶水密**
   - 需结合灌胶位置、被粘材质、固化条件和水下使用需求，完成环氧树脂 AB 胶的选型。
   - 完成灌胶工艺后，需检查固化效果、粘接与密封状态，并在整机下水前进行独立水密测试。

4. **整机配重设计**
   - 待所有设备安装完成后，根据整机实际重量、浮力、重心与浮心位置进行配重设计。
   - 确定配重质量、安装位置和固定方式后，通过静水试验调整整机浮沉状态与水下姿态。

### Clamp for Sonar 建模优化

根据新选型配重块的安装需求，已对 `Clamp for Sonar` 建模文件进行重新建模与结构优化。当前相关零件正在进行 3D 打印，待打印完成后开展实物试装验证。

### 后续验证

1. 使用新选型配重块试装打印件，检查夹具尺寸、安装孔位及固定效果是否符合要求。
2. 检查 `Clamp for Sonar`、声呐、配重块及周边外部结构之间是否存在干涉。
3. 检查紧固件装配空间、线缆通过性及夹具受力后的结构稳定性。
4. 根据试装结果继续调整模型；完成整机装配后，再通过静水试验验证配重位置对浮沉状态和水下姿态的影响。

## 2026-08-31 工作日志

### 今日工作

完成穿线螺栓的封灌处理及整机组装，并对组装后的密封舱进行了两次气密性测试。

### 第一次气密性测试与问题排查

第一次测试抽气过程中，真空度无法稳定保持，仪表读数持续下降，表明整机气密性不良。随后使用泡沫水对可能的泄漏位置进行涂抹检查，最终确认漏气位置位于穿线螺栓的线缆周边。

检查后发现，该处线缆周边封灌不充分并出现开裂。初步推测，灌胶后未将线缆保持固定直至胶体完全凝固，线缆在固化过程中发生移动，导致封灌层产生裂缝并形成漏气通道。

### 整改与第二次气密性测试

针对已确认的漏气位置，对穿线螺栓线缆周边进行了二次灌胶修补。待胶体凝固后重新开展气密性测试：将真空度抽至约 15 inHg，并持续保压 15 分钟，仪表读数未出现下降，气密性表现良好。

### 测试结论与后续注意事项

1. 本次漏气原因为穿线螺栓线缆周边封灌不良；二次灌胶后已通过 15 inHg、15 分钟的气密性复测。
2. 后续进行穿线螺栓灌胶时，需确保胶体充分填充线缆周边间隙，并在胶体完全固化前固定线缆，避免移动、拉扯或弯折造成封灌层开裂。
3. 正式下水前仍需复查灌胶部位的固化状态和外观，并结合后续装配情况再次进行整机气密性及水密性验证。

## 2026-09-02 工作日志

### 昨日气密复测与再次整改

昨日再次对整机进行气密性测试，测试过程中发现真空度下降较为明显，说明此前的密封处理仍未达到要求。针对穿线螺栓线缆周边重新进行灌胶处理，本次灌胶前增加了表面预处理步骤：

1. 使用 1500 目砂纸对线皮表面进行打磨粗化，以改善胶体与线皮之间的附着条件。
2. 使用 75% 酒精片擦拭打磨后的表面，清除残留粉尘及污物。
3. 完成表面处理后重新灌胶，并保持线缆位置固定，将灌胶部位静置过夜，等待胶体充分固化。

### 今日气密性测试

今日对静置固化后的整机再次进行气密性测试。将真空度抽至 15 inHg 后保压 15 分钟，期间仪表读数有轻微下降，但始终保持在 14～15 inHg 之间。根据本次测试结果，现阶段判断整机气密性合格。

### 浅水水密测试

气密性测试完成后，使用实验室小型水缸进行了水密测试。由于水缸尺寸有限，无法将整机一次性完全浸没，因此采用头部、尾部分别浸水的方式进行测试：

1. 测试前在密封舱内部放置干燥纸巾，作为进水检查指示物。
2. 将整机头部和尾部分别浸入水中，每次持续 20 分钟。
3. 每段浸水结束后，先将密封舱外表面的水擦干，再打开密封舱检查内部情况。
4. 检查发现舱内纸巾仍保持干燥，未发现明显进水迹象。

### 测试结论与后续计划

1. 本次气密复测在 15 inHg 起始真空度下保压 15 分钟，读数保持在 14～15 inHg，现阶段判定气密性合格。
2. 头部、尾部分别浸水 20 分钟后，舱内纸巾均未湿水，可初步判断整机通过当前条件下的浅水水密测试。
3. 本次水密测试受水缸尺寸限制，未实现整机同时、完全浸没，测试结果仅作为初步验证，不能替代完整水密测试。
4. 下次需更换尺寸更大的水池，使整机完全浸没，并适当延长测试时间，以进行更加严谨的整机水密性验证。

### 电池充电问题与方案准备

当前整机方案此前未充分考虑电池的日常充电操作，现有结构未预留便捷的外部充电接口。为避免影响后续调试与使用，现紧急准备临时充电方案和免拆卸充电方案两套路径。

#### 方案一：临时充电方案

该方案利用现有接口和延长线实现，充电时仍需打开密封舱：

1. 每次充电前取下密封舱半球罩。
2. 在电池 XT90 输出线上连接 XT90 一拖二接头，将电池主线分为两路。
3. 其中一路继续作为整机系统供电接口，另一路作为充电接口。
4. 充电接口通过 XT90 延长线引至舱外，与外部电源充电器连接。
5. 电池的 5 Pin 平衡充接口同样使用延长线加长，引出后连接充电器的平衡充接口。

该方案可作为近期调试阶段的临时解决方式，但每次充电均需拆卸半球罩，充电结束重新装配后还需检查端盖、密封圈及密封状态。

#### 方案二：免拆卸充电方案

拟设计一套 7 Pin 航空防水插头作为外部充电接口，将充电所需线路集中引出：

1. 使用其中 2 Pin 引出电池 XT90 主线的正、负两根导线。
2. 使用其余 5 Pin 引出电池平衡充接口的 5 根导线。
3. 在舱外制作与航空插头配套的充电转接线，使主充电线和平衡充电线能够同时连接充电器，从而实现无需拆卸半球罩的充电方式。

### 待确认与验证事项

1. 临时方案充电时应确保整机系统断电，并确认一拖二接头、延长线的极性、线序、线径和绝缘处理正确，避免误接或充电过程中向系统侧供电。
2. 需核对 5 Pin 平衡充延长线的逐针线序，保证各串电芯采样线与充电器端完全对应。
3. 需根据实际充电电流确认 7 Pin 航空防水插头中主充电端子的额定载流能力，同时检查插头的防反接、防误插及带防水盖方案。
4. 航空插头在舱体或端盖上的安装位置、开孔尺寸、固定方式、灌封工艺及周边结构干涉仍需完成设计和验证。
5. 免拆卸方案完成后，需分别验证充电功能、线序与温升，并重新进行整机气密性及水密性测试。

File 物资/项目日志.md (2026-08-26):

# AUV 物资管理日志

## 2026-08-18 工作日志

### 今日采购记录

根据 `采购清单.xlsx` 中的 2026-08-18 采购记录，今日已登记以下物资：

| 物资名称 | 规格/型号 | 数量 | 金额（元） |
|---|---|---:|---:|
| M10 密封舱实心螺栓 | 铝制密封螺丝 / M10 | 4 | 100 |
| M10 穿线螺丝 | 银色 / 不锈钢 / M10 | 9 | 270 |
| TS60 水下推进器 | 蓝黑 500KV 正桨 / 推荐 12 V 使用 | 3 | 567 |
| 35 A 双向无刷电调 | 35 A / 双向 / 水下动力 | 3 | 285 |
| 海目云水下机器人密封舱 | 外径 160 mm × 300 mm / 平盖+半球罩 / 赠密封圈和硅脂 | 1 | 1145 |
| 八合一大电流分电板 | 输入 XT90 / 输出 XT60 / 焊好出货 | 1 | 97.50 |
| XT90H 黑色母头带线 | XT90H 黑母头 / 8AWG / 10 cm | 1 | 10.12 |
| XT90H 黄色公头带线 | XT90H 黄公头 / 8AWG / 10 cm | 1 | 11.11 |
| 运费 | 分电板订单运费 | 1 | 5.00 |

更新后的 2026-08-18 采购清单共登记 9 项，表内商品数量合计 24，采购金额合计 2490.73 元。其中运费 5 元不计入实物资产；其余 8 类实物的数量合计为 23，资产原值合计 2485.73 元。

### 关联采购进展

与近期机械装配和电源布线问题直接相关的物资已在 2026-08-17 采购清单中登记：

1. XT60 母对母延长线：0.2 m、XT60 母对母、10AWG（5.3 mm²），数量 1 条。
2. M3 × 20+6 六角铜柱：20 颗/批，数量 1 批。
3. 线缆延长用红、黑色美标特软硅胶线：28AWG、10 米/卷，红色和黑色各 1 卷。

### 后续跟踪与验收

1. 上述记录表示物资已纳入采购清单，到货后仍需核对实际数量、规格、外观及功能。
2. 密封舱、实心螺栓与穿线螺丝到货后，需核对接口规格与装配配合，并在正式使用前完成密封性验证。
3. 推进器与电调到货后，需核对数量、型号、接口以及电气参数，并进行单套配对调试。
4. XT60 母对母延长线和 M3 × 20+6 铜柱到货后，需分别验证接口方向、线束布置空间以及螺纹配合长度。
5. 28AWG 延长导线的适用性需根据水下开关实际回路的电流和原线线径进一步确认，确认后再进行焊接延长。
6. 八合一分电板及 XT90H 带线接头到货后，需检查输入输出接口方向、线径、焊接质量与绝缘情况，并结合内部支撑结构验证放置和布线空间。

## 2026-08-25 工作日志

### 今日采购记录

根据 `采购清单.xlsx` 中的 2026-08-25 采购记录，今日已登记以下物资：

| 物资名称 | 规格/型号 | 数量 | 金额（元） |
|---|---|---:|---:|
| 密封舱气密性测试套装 | 真空枪+宝塔气嘴 / 工具箱套装 | 1 | 245.00 |
| 黑色快干 AB 环氧树脂胶 | 黑色快干款 / 5 分钟初固 / 两支装 / 送工具 | 1 | 15.10 |
| 4S6P 水下机器人锂电池 | 14.8 V / 18 Ah / 4S6P | 1 | 1552.00 |

今日共登记 3 类物资，数量合计 3 件，金额合计 1812.10 元。

### BOM 对应状态与验证事项

1. 密封舱气密性测试套装已作为通用工具纳入资产，可用于密封舱负压气密性测试，但不替代装机使用的泄压或抽真空测试阀。
2. 黑色快干 AB 环氧树脂胶已作为灌封胶/海工环氧的候选物资纳入 BOM，当前状态为“部分已有”；正式用于水密灌封前，仍需验证长期浸泡性能、与线皮及舱体材料的相容性，以及实际固化工艺。
3. 4S6P、14.8 V、18 Ah 电池已纳入第一版高容量动力电池条目，4S 电压匹配当前方案；18 Ah 低于 BOM 中建议的 20～30 Ah 区间，仍需验证外形尺寸、持续放电能力和整机续航时间。

## 2026-08-26 工作日志

### 今日采购记录

根据 `采购清单.xlsx` 中的 2026-08-26 采购记录，今日已登记以下物资：

| 物资名称 | 规格/型号 | 数量 | 金额（元） |
|---|---|---:|---:|
| M2.5 304 不锈钢六角螺母 | M2.5 / 100 个 | 1 批 | 2.46 |
| M2.5 尼龙平垫片 | M2.5 × 5 × 1 mm / 200 个 | 1 批 | 4.00 |
| M2.5 × 8 304 不锈钢十字圆头机牙螺钉 | M2.5 × 8 / 200 个 | 1 批 | 5.71 |
| M2.5 × 6 304 不锈钢十字圆头机牙螺钉 | M2.5 × 6 / 200 个 | 1 批 | 5.07 |
| M2.5 × 10 304 不锈钢十字圆头机牙螺钉 | M2.5 × 10 / 200 个 | 1 批 | 6.19 |
| 黑色自锁式尼龙扎带 | 4 × 150 mm / 黑色 / 500 根 | 1 批 | 17.39 |
| M3 × 20 304 不锈钢杯头内六角螺钉 | M3 × 20 / 50 个 | 1 批 | 1.12 |

今日共登记 7 类物资，采购批次数量合计 7，金额合计 41.94 元。

### 资产与 BOM 同步情况

1. `资产清单.xlsx` 已同步至 80 个资产条目、112 个实物采购数量，资产原值合计 8526.73 元。
2. 当前采购清单累计 81 类、113 个表内商品数量，采购总额为 8589.73 元；其中运费、快递费和打包费合计 63 元未纳入实物资产，采购与资产金额勾稽差额为 0。
3. 4 × 150 mm 黑色尼龙扎带已匹配“尼龙扎带与线束固定座”BOM 条目，但线束固定座尚未登记，当前仍为“部分已有”，后续需验证扎带的耐潮和老化性能。
4. M3 × 20 杯头内六角螺钉的长度与 BOM 一致，当前作为既有 M3 × 20 十字圆头螺钉的替代件或备件管理。
5. 今日登记的 M2.5 螺母、尼龙垫片及三种长度的 M2.5 螺钉尚未在 BOM 中明确对应装配位置，后续需结合结构图确认用途、实际需求量及材料适用性。

### 配重物资待同步事项

机械结构已依据新选型配重块对 `Clamp for Sonar` 进行重新建模，但现有采购清单与资产清单中尚未检索到该配重块的采购或入库记录，BOM 中“可调配重组件”仍标记为“待选型”。待新夹具打印试装确认后，需在物资表中补充配重块的规格、数量、价格、供应来源及采购状态，并同步更新 BOM 状态。

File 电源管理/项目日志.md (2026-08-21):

# AUV 电源管理项目日志

## 2026-08-16 项目回顾

### 方案资料

当前电源管理方案参考图：[AUV 电源管理方案](./AUV电源管理方案.png)。图中共记录两套供电路径：上方为当前主方案，下方为备用的副方案。

### 主方案（图片上方）

主方案以 14.8 V 4S 电池为主电源，电池通过 XT60 接口接入电源管理模块，并由水下开关参与系统通断控制。电源管理模块将主电源分为动力、飞控和主控三部分：

- 动力与补光支路：电源管理模块通过标注为“XT60、14.8 V、>50 A”的大电流输出接入具有 8 个 XT60 接口的分电板。分电板向 4 个电调和 2 盏补光灯供电，4 个电调分别驱动 4 个推进器。
- 飞控支路：电源管理模块的 Pixhawk 专用端子以 5 V/3 A（最大）直接向 Pixhawk 供电，再由 Pixhawk 向深度计提供 5 V 电源。Pixhawk 通过 4 路 PWM 信号控制电调，并通过 2 路 PWM 信号控制补光灯。
- 主控支路：电源管理模块的另一路 5 V/3 A（最大）端子通过 Type-C 公头转裸线线束向树莓派 4B 供电，树莓派再通过 USB 5 V 向声呐供电。Pixhawk 与树莓派之间通过 USB MAVLink 进行通信。

### 副方案（图片下方）

副方案保留了 14.8 V 4S 电池、水下开关、电源管理模块以及大电流分电支路。其与主方案的主要差异是 Pixhawk 供电路径：分电板将 14.8 V 电源引至 BEC，经 BEC 降压为 5 V 后向 Pixhawk 供电。树莓派 4B 仍由电源管理模块的 5 V/3 A（最大）端子供电。该方案作为主方案中 Pixhawk 专用供电路径的备选方案。

### 现存问题

1. 原独立调试阶段使用小容量电池，其输出接口为 XT60；后续整机将改用大容量电池，对应的输出接口为 XT90。现有电源管理板的输入接口为 XT60，无法直接兼容 XT90。目前尚未找到合适的替代电源管理板，该问题暂存，待后续解决。
2. 现有电源管理板的 XT60 线缆具有一定高度，需在内部支撑架 3D 打印件试装后，验证线缆及接头是否与密封舱内部结构发生干涉。

### 待验证项

1. 根据整机实际峰值与持续电流，核对大电流支路、电源管理板、分电板、XT60/XT90 接头及线束的额定能力。
2. 核对主方案中 Pixhawk 专用 5 V/3 A 端子的输出能力，确认其能够覆盖 Pixhawk 与深度计的供电需求。
3. 核对主方案中另一路 5 V/3 A 端子是否能够覆盖树莓派 4B、声呐及相关 USB 设备的稳态和瞬态负载。
4. 若启用副方案，需核对 BEC 的输出电压、电流能力及稳定性是否满足 Pixhawk 与深度计的供电需求。
5. 确认各支路的共地关系，并补充核对图中未明确标出的保险、过流保护、短路保护及接口防反接措施。
6. 待 3D 打印件完成试装后，检查 XT60 线束高度、转接线束布线空间以及接头插拔空间。

## 2026-08-17 工作日志

### 发现问题

水下开关的现有线缆长度不足，无法满足当前整机布线与装配需求。

### 后续处理

1. 结合实际安装位置和布线路径，确定需要增加的线缆长度。
2. 后续考虑采用焊接方式对水下开关线缆进行延长。
3. 延长后需检查焊点牢固性，并做好绝缘、密封及线缆应力保护，完成通断功能和布线试装验证。

### 待采购物料

1. XT60 母对母转接线。
2. 用于延长水下开关线缆的导线。

## 2026-08-18 工作日志

### 电源管理方案 2.0

电源管理方案已更新至 2.0 版，方案图见：[AUV 电源管理方案 2.0](./AUV电源管理方案2.0.png)。2.0 版不再区分原有主、副两套供电路径，而是以单一供电架构作为当前方案。

### 2.0 版供电架构

系统继续使用 14.8 V 4S 电池作为主电源，并由水下开关参与系统通断控制。电源管理模块分别为动力与补光支路、飞控支路和主控支路供电：

- **主电源输入**：14.8 V 4S 电池通过 XT90 接口接入电源管理模块，取代原方案中的 XT60 输入。
- **动力与补光支路**：电源管理模块通过标注为“XT90、14.8 V、>50 A”的大电流输出向分电板供电。分电板仍标注为 8 路 XT60，用于向 4 个电调和 2 盏补光灯供电，4 个电调分别驱动 4 个推进器。
- **飞控支路**：电源管理模块的 Pixhawk 专用端子继续以 5 V/3 A（最大）向 Pixhawk 供电，再由 Pixhawk 向深度计提供 5 V 电源。Pixhawk 通过 4 路 PWM 控制电调，通过 2 路 PWM 控制补光灯。
- **主控支路**：电源管理模块的另一路 5 V/3 A（最大）端子继续通过 Type-C 公头转裸线线束向树莓派 4B 供电，树莓派再通过 USB 5 V 向声呐供电。Pixhawk 与树莓派之间继续使用 USB MAVLink 通信。

### 与原方案的主要变化

1. 电池至电源管理模块的主电源接口由 XT60 改为 XT90。
2. 电源管理模块至分电板的大电流输出接口由 XT60 改为 XT90。
3. 原方案中使用 BEC 为 Pixhawk 供电的副方案不再作为 2.0 版的当前供电路径。
4. Pixhawk、树莓派 4B、深度计、声呐、补光灯和电调的供电与控制逻辑基本保持不变。

### 问题状态更新

1. 原方案中“大容量电池 XT90 输出与电源管理板 XT60 输入不兼容”的问题，已在 2.0 方案层面通过将主电源输入改为 XT90 进行处理。实际电源管理模块的型号、接口和额定能力仍需在硬件选型或改造后确认。
2. 由于接口已调整为尺寸更大的 XT90，原有 XT60 接口的机械干涉结论需重新评估。需根据 XT90 接头、线束和弯曲空间重新修改安装结构及避让空间。
3. 水下开关线缆长度不足的问题不受本次方案更新影响，仍需按既定计划进行延长与绝缘、密封处理。

### 待验证项

1. 确认拟用电源管理模块已配置 XT90 输入及 XT90 大电流输出，并核对其持续电流、峰值电流和散热能力。
2. 图中电源管理模块至分电板的连接标注为 XT90，但分电板仍标注为 8 路 XT60，需确认分电板的实际输入接口，以及是否需要 XT90 转接线或更换分电板。
3. 根据 4 个推进器、2 盏补光灯和其他负载的实际工况，重新核算主干线和各分支的持续电流与峰值电流，并核对 XT90、XT60、分电板和线束的额定能力。
4. 验证两路 5 V/3 A 输出分别对 Pixhawk 与深度计、树莓派 4B 与声呐供电时的稳态和瞬态负载能力。
5. 完成 XT90 接口周边结构修改后，通过 3D 打印与整体试装检查接头、线束、弯曲半径及插拔空间。

## 2026-08-21 工作日志

### 完成事项

1. 已在电源管理板的输入端和输出端分别焊接 XT90 延长线，完成电源管理方案 2.0 中 XT90 主干接口的实物改造。
2. 电源管理板输出端已连接一拖八分电板，并完成基本连接与供电功能测试。

### 测试结果

电源管理板与一拖八分电板连接后功能测试正常，当前连接方案可用。本次结果为现阶段基本功能验证，后续整机装配后仍需进行带载与稳定性测试。

### 下一步工作

1. 结合密封舱内部空间、支撑架结构及其他电子设备布置，确定一拖八分电板的安装位置。
2. 设计分电板的固定方式，并为 XT90 主干线、各路 XT60 分支线及接头插拔预留足够空间。
3. 完成分电板放置与固定后，复查线束干涉、焊点应力、绝缘防护与散热条件，并再次进行通电测试。

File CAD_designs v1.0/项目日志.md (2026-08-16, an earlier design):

# CAD 设计项目日志

## 2026-08-16 项目回顾

本版装配体建模文件中的密封舱沿用 CavePI 项目的开源模型。经加工可行性评估，发现该开源密封舱的建模尺寸较为特殊，许多淘宝商铺无法按该规格进行定制加工。若考虑独立加工，法兰和金属垫圈则需通过 CNC 定制加工；但由于需求数量较少，定制加工难度较大且成本较高。综合考虑加工可行性与成本，现阶段暂时放弃基于该开源密封舱的本版方案。

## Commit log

2026-08-10 Initial CAD design import
    [Ballast Weight.SLDPRT, Basic ESC.SLDPRT, Battery Junction.SLDPRT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]
2026-08-10 替换电源模块（问题xt60干涉）
    [Battery Mounting_Bottom Plate.SLDPRT, 电源模块.SLDPRT, 装配体1.SLDASM]
2026-08-10 添加M3沉孔
    [Battery Mounting_Bottom Plate.SLDPRT, Battery Mounting_Left Plate.SLDPRT, Standoff_M3x0.5_37 mm_Male to Female.SLDPRT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]
2026-08-16 重构github仓库框架
    [Ballast Weight.SLDPRT, Basic ESC.SLDPRT, Battery Junction.SLDPRT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]
2026-08-16 增加了日志文件，电源管理和物资文件夹
    [Ballast Weight.SLDPRT, Basic ESC.SLDPRT, Battery Junction.SLDPRT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]
2026-08-17 优化电池安装圆板与装配体并记录首轮试装问题
    [Battery Mounting_Circular Plate top.SLDPRT, Battery Mounting_Circular Plate.SLDPRT, 装配体2.SLDASM]
2026-08-17 记录水下开关线缆延长方案与转接线采购需求
2026-08-18 完善外部夹具与XT90供电方案并更新物资台账
    [CavePI水下机器人BOM.xlsx, Clamp for Horizontal Thrusters.SLDASM, Clamp for Horizontal Thrusters_Left.SLDPRT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]
2026-08-19 按实测线径适配水平推进器夹具线槽
    [Clamp for Horizontal Thrusters.SLDASM, Clamp for Horizontal Thrusters_Left.SLDPRT, Clamp for Horizontal Thrusters_Right.SLDPRT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]
2026-08-20 更新AUV v2.0总装配体并补充当日汇总
    [装配体2.SLDASM]
2026-08-21 完成XT90主干接口改造及分电板供电测试
2026-08-24 暂存内部支撑加层分电板方案
    [Battery Mounting_Bottom Plate.SLDPRT, Clamp for Sonar(with components).SLDASM, Mounting Plate_PowerModule.SLDPRT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]
2026-08-24 回退内部支撑加层方案并保留日志
    [Battery Mounting_Bottom Plate.SLDPRT, Clamp for Sonar(with components).SLDASM, Mounting Plate_PowerModule.SLDPRT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]
2026-08-24 重构电源管理板与分电板安装布局
    [Battery Mounting_Bottom Plate.SLDPRT, Battery Mounting_Top Plate.SLDPRT, Battery Mounting_behind Plate(with components).SLDASM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]
2026-08-24 补全新布局子装配与总装配体保存
    [Battery Mounting_Right Plate(with components).SLDASM, Clamp for Sonar(with components).SLDASM, Standoff_M3x0.5_12 mm_Male to Female.SLDPRT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]
2026-08-25 同步新布局右侧子装配与总装配体
    [Battery Mounting_Right Plate(with components).SLDASM, 装配体2.SLDASM]
2026-08-26 完成一端法兰配合的一体抽拉式整机装配
    [Ballast Weight.SLDPRT, Battery Mounting_Top Plate.SLDPRT, Battery Mounting_behind Plate(with components).SLDASM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]
2026-08-26 重构声呐配重夹具并同步紧固件物资台账
    [Ballast Weight.SLDPRT, CavePI水下机器人BOM.xlsx, Clamp for Sonar(with components).SLDASM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]
2026-08-27 优化声呐夹具零件与子装配结构
    [Clamp for Sonar(with components).SLDASM, Clamp for Sonar_Bottom.SLDPRT, Clamp for Sonar_Top.SLDPRT]
2026-09-01 调整内部支撑与声呐平台装配结构
    [Battery Mounting_Circular Plate top.SLDPRT, Clamp for Vertical Thrusters_Mid.SLDASM, Mounting Plate_connect_Flange.SLDPRT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]
2026-09-01 记录穿线螺栓补胶及整机气密性复测结果
2026-09-01 补录密封配重照明及焊锡采购并同步物资台账
    [CavePI水下机器人BOM.xlsx, 资产清单.xlsx, 采购清单.xlsx]
2026-09-02 通过整机浅水密封验证并规划免拆充电接口
    [CavePI水下机器人BOM.xlsx, 资产清单.xlsx, 采购清单.xlsx]
2026-09-05 记录9月4日各子项目日志巡检结果
2026-10-30 当前更新为第一版的保留建模；后续将大范围更新建模（添加垃圾回收装置、更改舱内框架布局等）
2026-10-30 docs: 更新第一版原型实物展示照片
